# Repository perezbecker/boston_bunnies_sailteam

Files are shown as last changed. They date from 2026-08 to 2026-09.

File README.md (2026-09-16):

# Boston Bunnies Sail Team

Boat designs of the Boston Bunnies Sail Team — small, printable, self-steering sailing
models. Each boat is a parametric FreeCAD macro plus the spec and renders that go with
it.

## Fleet

| Boat | Current | What it is |
|---|---|---|
| [**Lahar**](boats/lahar/) | v2 one-piece prototype | Rounded deck-down body with attached amas, beams and skeg. 220 mm, approximately 318 g all-up, solid vane, four-bolt yard clamps, keyed steering mounts and MK4S files. |

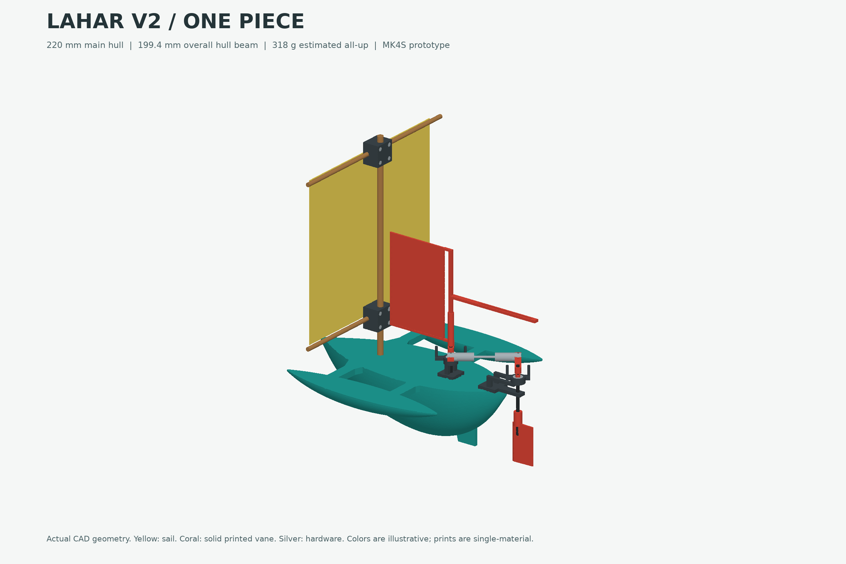
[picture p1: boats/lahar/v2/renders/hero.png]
Lahar v2


## Repository layout

```
boats/<name>/
  README.md          current-version entry point and version history
  v2/                all assets for the current prototype
    cad/             parametric macro, FreeCAD/STEP files and generation scripts
    docs/            design and assembly guide
    print/           STLs, self-contained 3MFs and printer-specific G-code
    renders/         CAD-derived reference views
    reports/         software checks and engineering estimates
  versions/v1/       frozen previous assets, including their original print jobs
```

The boat README points to the current version. Starting with Lahar v2, current
assets live in an explicit version directory, as requested for this prototype.
The source is [boats/lahar/v2/cad/lahar.FCMacro](boats/lahar/v2/cad/lahar.FCMacro).
Superseded assets remain under `versions/`; never rebuild or overwrite the archive.

## Working on a design

The macro is the single source of truth. Everything else — the dimensions in the spec,
the figures printed on the renders — is a snapshot derived from it. To change a design,
edit the parameter constants at the top of the macro and regenerate, rather than
hand-editing the derived numbers downstream. Numbers that get hand-patched in one place
and not another are how a spec and a render end up disagreeing about the same boat.

See [boats/lahar/versions/README.md](boats/lahar/versions/README.md) for preservation
rules. A valid model and completed slice do not prove watertightness or sailing
performance; each version records its outstanding physical tests.

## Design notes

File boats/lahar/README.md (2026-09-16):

# Lahar

A small mechanical self-steering downwind trimaran. No electronics.

**Current design: [v2 one-piece prototype](v2/README.md), revised 2026-09-15.**
The enclosed main hull, amas, beams and skeg print together **deck-down**, with
continuous rounded bottoms and no glued lids or ama joints. The body is 220 mm
long, 199.4 mm wide, and the boat is approximately 318 g nominal all-up. A solid
printed vane, two four-bolt yard clamps and recessed steering-mount guides are
included. All assets are together in [v2](v2/).

Lahar v2

## Build v2

- [MK4S printing instructions](v2/instructions.md)
- [Design, material reuse and assembly](v2/docs/design-spec.md)
- [Clamp and keyed-mount details](v2/renders/assembly-details.png)
- [FreeCAD assembly](v2/cad/Lahar_v2.FCStd) and [source macro](v2/cad/lahar.FCMacro)
- [USB G-code](v2/print/usb/) and [PrusaSlicer projects](v2/print/projects/)
- [Renders](v2/renders/) and [validation reports](v2/reports/)

Files are for the confirmed **MK4S, stock 0.4 mm high-flow nozzle, PLA, smooth
PEI, no MMU**. All parts fit in two jobs. Print the steering/clamps/coupon job
first, check fit, then print the body. Software checks passed; the prototype
has not been physically printed, seal-tested or sailed. The clevis's fork gap
still needs a fit check. Do not use v1's CORE One+ G-code on the MK4S.
Both yard clamps together need eight M2 x 16 socket-cap bolts and eight standard
M2 hex nuts. The steering stands locate in their recessed keys and are glued
to the deck; there are no screw holes into the hull.

## Version history

| Version | Status | Record |
| --- | --- | --- |
| [v2](v2/README.md) | Current one-piece prototype; software checked | Integrated rounded body, solid vane, two four-bolt clamps, recessed steering guides and two MK4S jobs |
| [v1](versions/v1/) | Archived; physically printed by the owner | Original assets preserved unchanged; [field observations](versions/v1/FIELD-NOTES.md) record leakage and fit problems |

The older pre-audit draft remains in git history at `4af5a90`; it was never a
separate printed version. See the [versioning rules](versions/README.md).

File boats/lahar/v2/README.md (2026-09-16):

# Lahar v2

Downwind trimaran prototype for the **Prusa MK4S, stock 0.4 mm high-flow nozzle,
ordinary PLA, smooth PEI, no MMU**. Prepared 2026-09-15.

**One-piece revision:** the enclosed main hull, both amas, beams and skeg print
together, upside down, with a continuous rounded exterior. There are no separate
lids or ama joints. This replaces the earlier modular v2 draft.

**Rigging update:** the wind vane is now solid printed plastic, both yards have
four-bolt clamp sets, and both steering stands have matching recessed deck keys.
Use the updated body and steering jobs together. The clamps need **eight M2 x 16
socket-cap bolts and eight standard M2 hex nuts** in total, supplied separately.

**Software-validated, not physically printed or sailed.** Watertightness and
steering authority are acceptance tests, not promises from a CAD model.
Print the combined small-parts job first and use its coupon to check fit before
printing the body. The clevis's internal fork gap is still unknown.

Lahar v2 assembly

## Start here

- [Printing instructions](instructions.md): two USB jobs, fit checks, and MK4S setup.
- [Design and assembly guide](docs/design-spec.md): sealing, linkage, weight budget, and test procedure.
- [Clamp and steering-mount details](renders/assembly-details.png): exploded assembly views.
- [Native FreeCAD assembly](cad/Lahar_v2.FCStd) and [STEP assembly](cad/Lahar_v2.step).
- [Parametric source macro](cad/lahar.FCMacro): edit parameters here to regenerate.
- [G-code](print/usb/), [self-contained 3MF projects](print/projects/), and [16 print-oriented STLs](print/stl/).

## What changed

The body restores v1's integrated, deck-down construction. Smooth half-ellipse
lofts form all three rounded hulls. The CAD has a measured **1.8 mm minimum
skin**, 0.9 mm ribs and 46 enclosed flotation cells. Hidden 45-degree roofs
close to a 0.6 mm gap, avoiding broad unsupported closures. Four perimeters
replace v1's two. The final body slice has no warnings or removable supports.
The rudder shaft stays outside the hull, eliminating that wet penetration.
Leak-testing is mandatory; a thin external seal coat may still be needed.

The quarter-chord rudder has **10.7 mm minimum clearance over its complete swept
envelope**. Both stocks use the existing 623ZZ bearings with short, loose lower
guides and inner-race spacers. The clevis tabs are **1.8 mm thick with 2.3 mm
holes**. A **64 x 96 mm solid vane with a 1.0 mm web** restores the printed blade,
with about 4.5 times v1's aerodynamic area-times-lever. Its extended counterweight
slot accommodates the extra weight. The existing 45 mm rod and clevises
form a nominal 64 mm pin-to-pin linkage; actual insertion depth needs checking.

Each yard has three printed clamp pieces and four bolts/nuts, holding the existing
6 mm mast and 4 mm yard without intersecting the rods. The steering stands fit
distinct asymmetric recesses with 1.8 mm of intact hull backing. Dry-fit them in
their keys, then bond the bases; the recesses are not snap fasteners or screw holes.

This is a conservative, heavier prototype: **220 x 199.4 x 65.2 mm body print,
about 318 g nominal all-up**, rather than v1's approximately 106 g target.
The forward hull sections have been filled out to carry the clamps and solid
vane. Minimum deck freeboard is calculated at 13.9 mm nominally and 12.4 mm at
a 350 g loading check. These are static estimates, not a certified payload or
wind rating. At 10 degrees of heel in the conservative-weight case, the low-side
deck is almost awash. Use sheltered water and verify the physical boat before sailing.

## Printer files

| Job | Time estimate | PLA including waste |
| --- | --- | --- |
| Steering, both clamp sets and fit coupon, 15 parts | 6 h 5 min | 58.03 g |
| One-piece body with locating recesses | 26 h 3 min | 238.82 g |

Total: **32 h 8 min and 296.85 g**, including the coupon and removable waste.
All 16 parts are included exactly once; only their placement and job grouping
changed. The body stays on its own bed. Have 350 g of PLA available.
Colors in the renders distinguish materials; all G-code jobs are single-material.

**The slicing is not identical to v1.** Deck-down printing and 0.15 mm layers are retained,
but the MK4S-specific printer preset, shell construction, perimeter count, solid
layers, and support layout are different. Never run the archived CORE One+ G-code
on the MK4S. The MK4S print volume is **250 x 210 x 220 mm**.

## More views and evidence

[One-piece body and print orientation](renders/one-piece-body.png) | [Hull section](renders/hull-section.png) |
[Steering](renders/steering-gear.png) | [Clamps and mount guides](renders/assembly-details.png) |
[Print layouts](renders/print-layouts.png)

The [CAD checks](reports/cad-validation.json), [slicing checks](reports/print-validation.json),
[engineering estimates](reports/engineering.json), and [render checks](reports/render-validation.json)
record what was verified. No physical hardware fit, seal, bearing friction, or
on-water steering test has been performed.

The untouched predecessor is in [versions/v1](../versions/v1/).

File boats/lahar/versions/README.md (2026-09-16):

# Archived Lahar versions

## v1

[v1](v1/) preserves the complete previous design: its original README, printing
instructions, macro, export and slicing scripts, design specification, renders,
STLs, two 3MF projects and two CORE One+ G-code files. All original files were
compared byte-for-byte before the root-level duplicates were removed.

[FIELD-NOTES.md](v1/FIELD-NOTES.md) records the owner's 2026-09-15 observations
and why v2 replaces it. The archived original README and instructions are
historical snapshots; their older "not yet printed" wording and root-relative
rebuild examples have deliberately not been rewritten.

**Do not rebuild inside this archive.** Its scripts overwrite generated files
beside themselves. Copy a version to a separate work area before investigating
or rebuilding it. Never run these CORE One+ jobs on the MK4S.

## Current-version layout

The current design is [../v2](../v2/). Starting with v2, each active iteration
has its own explicit directory containing all its assets, and the boat README
points to it. This replaces v1's convention of putting active CAD and print
folders directly at the boat root.

## Preserve a future version

1. Record the physical observations, measured mass, water uptake, hardware
   dimensions and steering tests before changing anything.
2. Preserve the complete previous directory, including instructions, reports
   and printer files, under `versions/vN`. Do not copy only CAD and renders.
3. Verify every original file against the archive before removing a duplicate.
4. Create the next active directory, update the macro/document version, and
   regenerate its CAD, meshes, projects, G-code, reports and renders together.
5. Update the boat README and fleet entry. Clearly distinguish software checks
   from physical validation, and identify the exact printer/nozzle/material.

An archive's original assets are immutable. Add a separate field-notes file for
later observations instead of rewriting old evidence or hand-patching old G-code.

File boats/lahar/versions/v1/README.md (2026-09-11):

# Lahar

A **self-steering downwind trimaran** — a 200 mm, ~106 g model yacht that prints as one
piece, carries a square sail on a dowel mast, and holds its course with a mechanical
wind vane driving the rudder. No electronics.

**Current version: v1** (designed, not yet printed).

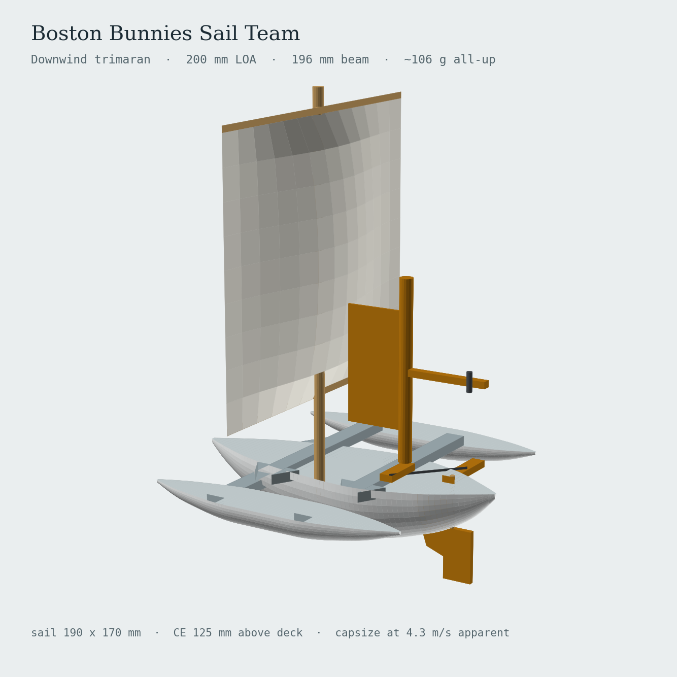
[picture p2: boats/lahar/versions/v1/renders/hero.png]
Hero render


## Files

| Path | What it is |
|---|---|
| [`cad/lahar.FCMacro`](cad/lahar.FCMacro) | Parametric FreeCAD macro — generates every printed part |
| [`instructions.md`](instructions.md) | CORE One+ USB printing instructions, settings, and first-print caveats |
| [`print/usb/`](print/usb/) | Two ready-sliced G-code jobs for a CORE One+, stock 0.4 mm high-flow nozzle, PLA, smooth PEI |
| [`print/projects/`](print/projects/) | Editable PrusaSlicer projects with settings and side-float infill modifiers |
| [`print/stl/`](print/stl/) | Five checked, print-oriented meshes in millimetres |
| [`cad/export_print.py`](cad/export_print.py), [`cad/slice_print.py`](cad/slice_print.py) | Rebuild the meshes, projects, and printer files |
| [`docs/design-spec.md`](docs/design-spec.md) | Design spec and build guide: dimensions, weight budget, rigging, tuning, BOM |
| [`renders/`](renders/) | Reference renders |
| [`versions/`](versions/) | Superseded iterations (empty — v1 is the first) |

## Print from a USB drive

For the confirmed **Prusa CORE One+, stock 0.4 mm high-flow nozzle, PLA, and smooth
PEI sheet**, use the two files in [print/usb](print/usb/) and follow
[instructions.md](instructions.md). No further slicing is needed for that setup.
The body takes about 4 h 27 min and steering about 1 h 20 min.

These are **first-test files, not physically validated prints**. The hollow body
still produces a PrusaSlicer "Floating bridge anchors" warning; read the guide's
caveat and inspect its Preview before printing. The steering parts include
removable supports. Assembly still needs the hardware and rig in the design spec.

## Generate from CAD

1. Open FreeCAD (the current export was checked with 1.1.3) and go to **Macro → Macros… → Execute**,
   pointing at `cad/lahar.FCMacro`.
2. The macro builds five parts in a document named `Lahar_v1`:
   `Trimaran_Body`, `Rudder_Blade`, `Rudder_Tiller`, `Vane_Paddle`, `Vane_Arm`.
3. Export them as STL. The macro has a commented-out export block at the bottom if
   you'd rather batch it.
4. Slice the body **deck-down** — flip 180° about X. Everything on deck is a recess,
  so the intended orientation needs no external supports; internal bridging still
  needs a test print. Main hull at 4 % infill, amas at 0 % — they are floats, and
  the weight budget assumes it. The ready-made STLs are already flipped.
5. Build the sail and rig from the [spec sheet](docs/design-spec.md); mast, yards,
   bearings and pushrod are off-the-shelf parts.

To change the design, edit the `PARAMETERS` block at the top of the macro and re-run.
Hull stations, ama placement, mast position, skeg size and arm hole spacing are all
driven from there.

## Principal dimensions

| Item | Value |
|---|---|
| Length overall | 200 mm |
| Beam overall | 196 mm |
| All-up weight | ~106 g |
| Design waterline | ~16 mm below deck, amas clearing by 1.4 mm |
| Sail | 190 × 170 mm square, on mast + two yards |
| Print footprint | 200 × 196 × 46 mm — fits a 220 × 220 bed |

Full numbers, weight budget and bill of materials live in [`docs/design-spec.md`](docs/design-spec.md).

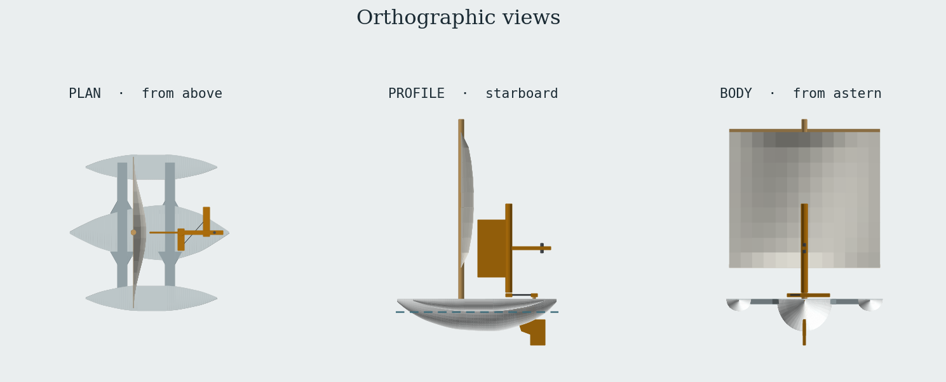
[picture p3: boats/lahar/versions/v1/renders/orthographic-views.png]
Orthographic views


## How the steering works

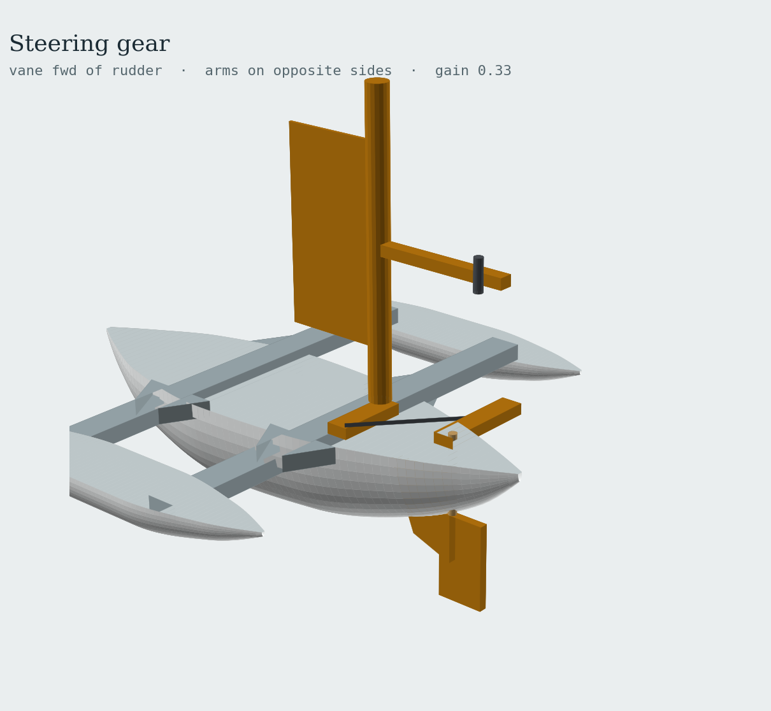
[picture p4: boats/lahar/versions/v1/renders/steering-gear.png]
Steering gear


*(Linkage geometry is current; the hull in this view predates the hull refinement.)*

A wind vane forward of the rudder is linked to the tiller by an adjustable pushrod.
Three details make or break it, and all three are easy to get wrong:

* **Arms on opposite sides.** Vane arm to port, tiller arm to starboard. The reversal
  is what makes a course error push the bow *back*. Same side and the boat spirals.
* **Balance the vane.** Slide the M3 screw along the counterweight slot until the
  paddle sits indifferent at any angle with the boat heeled 10–15°. An unbalanced
  vane steers to the low side, not to the wind.
* **Gain = vane hole radius ÷ tiller hole radius.** Start at 6/18 ≈ 0.33. Fishtailing
  means go smaller; lazy wandering means go larger.

The single centerline skeg supplies the damping — there are no fins on the amas.
Sail effort sits forward at 40 % LOA and lateral resistance sits aft, a 21 % LOA
separation, which is what keeps the boat tracking downwind instead of sliding sideways.

Below about 0.7 m/s of apparent wind the vane has too little torque to hold a course
and will wander. That is inherent to a vane this size, not a build fault.

## Stability, and why the rig is short and wide

The amas *are* the stability — the main hull alone has negative GM and will loll a
degree or two until one ama takes up. Normal trimaran behaviour.

Sail centre of effort sits 125 mm above deck. One fully buried ama gives 30 mN·m of
righting moment, which sets the capsize threshold at roughly 4.3 m/s apparent wind in
a 30° gust; comfortable sailing is up to ~3.3 m/s. Because apparent wind downwind is
true wind *minus* boat speed, the boat is most vulnerable at the moment you release
it, before it accelerates.

Two findings drove the current proportions:

* **Trading sail height for width is free stability.** An earlier 160 × 200 sail on
  a 330 mm mast put the CE at 190 mm and capsized at ~3.5 m/s. Same area at 190 × 170
  on a 250 mm mast raised the threshold to 4.3 m/s — 21 % more wind for free.
* **Lengthening the main hull does nothing for heel resistance.** BM_T = I_T/V and
  both scale with length, so stretching 200 → 280 mm leaves BM_T unchanged while
  adding 40 % wetted area. Heel resistance is a beam property. The amas were
  lengthened to 165 mm and their sections grown instead — +58 % righting moment
  inside the same footprint.

## Design notes

The trimaran was chosen over a monohull, catamaran or proa because the amas carry no
load, so they need no precision to work. The amas are double-ended (transoms only pay
off above Froude ≈ 0.5, far beyond this scale) and finless. A cross-sail was rejected
for destabilizing the vane, and a keel for adding harmful lateral area downwind.
Upwind capability is deferred — it would need a cambered sail, a daggerboard forward,
and the CE/CLR order reversed.

The design was settled by a full end-to-end audit — mass build-up, equilibrium
waterline, trim, stability, balance — which raised the weight budget from an optimistic
95 g to 106 g, widened the main hull and shifted its volume aft to cure a 5.7° stern
squat, re-proportioned the amas, and deepened the skeg and rudder to keep grip under
the deeper hull. The boat floats with a deliberate +2.3° stern-down trim, which
lightens the bow and helps it track.

Background and the reasoning behind these choices:
[design conversation](https://claude.ai/share/8d004267-fff6-457e-bb1f-0c273a21cccd)
(25 Aug 2026).

## Version history

| Version | Status | Notes |
|---|---|---|
| **v1** | current | Audited design: 196 mm beam, ~106 g, 190 × 170 sail, 165 mm amas. Not yet printed. |

An earlier pre-audit draft (191 mm beam, ~95 g, 160 × 200 sail on a 330 mm mast) was
superseded before anything was printed and is not carried as a version. It remains in
git history at commit `4af5a90` if you ever want to look at it; the stability section
above explains why its rig was cut down.

See [`versions/README.md`](versions/README.md) for how the next iteration gets cut.

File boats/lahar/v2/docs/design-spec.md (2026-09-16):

# Lahar v2: design and assembly

Boston Bunnies Sail Team, 2026-09-15. Source of truth:
[lahar.FCMacro](../cad/lahar.FCMacro). Generated estimates are in
[engineering.json](../reports/engineering.json).

**This is an untested physical prototype.** The design addresses v1's reported
leaks, rudder interference, clevis mismatch and steering-friction concerns.
No software check can certify an FDM hull as watertight or establish the friction
of the user's bearings. Complete the acceptance tests before open-water use.

## Design decisions

1. **Restore v1's one-piece, upside-down construction.** The main hull, both
   amas, two crossbeams, gussets and skeg form one enclosed solid. The continuous
   deck sits on the print bed; all three rounded bottoms grow upward. There are
   no separately printed lids, bonded ama joints or skeg attachment pad. This
   revision replaces the earlier modular v2 draft at the owner's request.
2. **Thicker skins and printable hidden closures.** Smooth half-ellipse lofts
   preserve the rounded exterior. Scaled internal cavities leave a CAD-measured
   minimum 1.8 mm skin, including the deck. Four perimeters replace v1's two.
   Internal 0.9 mm ribs at 12 mm spacing divide the hulls into 46 closed cells:
   18 in the main hull and 14 in each ama. Each cell has a 45-degree internal
   roof closing to a 0.6 mm gap. Only these hidden roofs are angled; the outside
   remains rounded. This avoids the floating bridge anchors encountered with
   simply hollowing the rounded body. Final slicing reports no warnings.
3. **No wet rudder penetration.** The rudder stock and its lower guide are on
   an external stern bracket. The mast well has a closed floor. Only the small
   steering stands bond onto the already closed deck. Distinct recessed keys
   locate them without screws into buoyancy chambers; those joints are not hull seals.
4. **Lower-load steering with the existing hardware.** Keep the two 623ZZ
   bearings and carbon stocks. Use short clearance guides, inner-race spacers,
   a quarter-chord rudder, thin clevis tabs and indexed cranks. The vane is now
   solid printed plastic again, with a 1 mm web and an extended counterweight slot.
   There is still plain-guide and clevis friction; the system is not frictionless.
5. **Four-bolt yard clamps.** Two three-piece clamp sets attach the existing
   6 mm mast to the two 4 mm yards. Each uses four M2 x 16 socket-cap bolts and
   four captive M2 nuts. The yards sit just forward of the mast so the rods
   do not intersect. Added plastic, hardware and counterweights are included
   in the revised mass calculation; the hull's forward sections are slightly fuller.

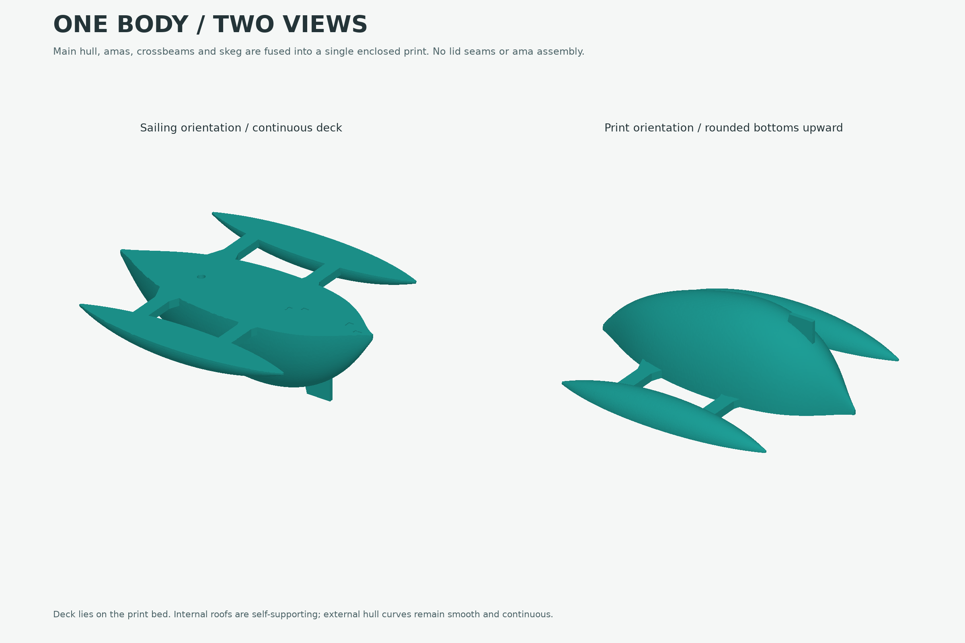
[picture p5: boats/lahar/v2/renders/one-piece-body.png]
One-piece body in sailing and print orientation


## Dimensions

Coordinates are millimetres: X runs bow to stern, Y is positive to starboard,
Z is upward. The continuous deck is Z=1.2, retained from the steering layout.

| Item | v2 |
| --- | --- |
| Main hull, measured mesh | 220 long x 79.46 maximum beam x 64.21 deep |
| One-piece body print bounds | 220 x 199.41 x 65.20 |
| Amas, measured mesh | 178 x 33.41 x 16.72; bows at X=22; centerlines Y=+/-83 |
| Main hull bottom | Continuously rounded; lowest mesh point Z=-63.01 |
| Minimum outer skin / continuous deck | At least 1.8 / 1.8 |
| Integral crossbeams | 12 x 180 x 6; leading edges X=60 and 132, flush with deck |
| Internal ribs / roofs | 0.9 thick, 12 pitch; 45-degree slopes, 0.6 final gap |
| Mast well | X=70; bore 6.4; insertion 24; closed floor 1.8 |
| Vane / rudder axes | X=154 / 234; Y=0 |
| Steering mount keys | Four blind recesses, 0.8 deep; matching feet 0.6 high; 1.8 minimum backing |
| Bearings | 623ZZ, 3 x 10 x 4; pockets 10.2 x 4.2 |
| Bearing top / linkage tab bottom | Z=19.8 / 24.2 |
| Lower guide bore | 3.8, short and accessible |
| Printed stock sockets | 3.2 |
| Rudder | 24 chord x 40 span; Z=-28 to -68; 25% chord pivot |
| Rudder cylindrical boss | 8 diameter, 14 high; Z=-30 to -16 |
| Full rudder sweep clearance | 10.71 minimum to the complete body and integral skeg |
| Integral skeg | X=150 to 184, 3 thick; tip Z=-64 |
| Solid printed vane | 64 x 96 area, 1.0 web, 1.2 rim; no film |
| Vane aerodynamic center lever | 40 from axis |
| Vane counterweight slot | 35 to 95 from axis |
| Vane / tiller gain holes | 12, 15, 18 / 30, 36, 42 |
| Clevis tabs / pivot holes | 1.8 thick / 2.3 diameter |
| Neutral pin-to-pin length | 64 with the 12/36 hole pair |
| Assembled length including centered rudder | 252 |
| Neutral length including longer counterweight arm | 256 |
| Yard centers | X=62.6; Z=40 and 210; 7.4 forward of mast |
| Yard clamps | Two sets of three 22 x 22 pieces; four M2 bolts/nuts per set |
| Clamp groove diameters / split gaps | 6.2 mast, 4.2 yard / 0.4 on each side of middle saddle |

The whole 220 x 199.41 mm body fits the **250 x 210 mm MK4S bed** with its brim.
Only the steering parts, clamp pieces and fit coupon print separately. The
rudder and longer counterweight arm extend beyond the printed body.
Loft interpolation makes measured dimensions differ slightly from station values.

## Weight and flotation

| Component group | Nominal mass |
| --- | --- |
| One body, eight steering parts and six clamp pieces, at PLA density 1.24 g/cm3 | 277.61 g |
| Mast, two yards, sail and rigging | 9.69 g |
| Carbon stocks | 1.52 g |
| Two 623ZZ bearings | 3.40 g |
| Metal clevises, screws and 45 mm rod | 6.00 g |
| Eight M2 x 16 clamp bolts and eight M2 nuts | 5.60 g |
| Fore-aft counterweight and lateral balance nuts allowance | 4.50 g |
| Adhesive and seal coat allowance | 10.00 g |
| **Nominal all-up** | **318.32 g** |

Hardware masses, wood density, cloth weight and seal-coat mass are assumptions,
not measurements. Cloth is budgeted at 30 g/m2. Weigh the actual parts.
The body alone is 239.77 g by CAD volume; both clamp sets together are 16.49 g.
The complete solid vane including its spine and counterweight arm is 10.33 g.
The two print jobs consume 296.85 g, including the coupon, supports and brims.
The coupon now shares the steering bed, but is never part of the boat's displacement.
Subtracting its 8.57 g CAD material estimate leaves 288.28 g; counting all the
remaining waste as if it stayed on the boat gives a conservative **328.99 g** case.
Repacking does not change the nominal assembled mass or center of gravity.

| Fresh-water case | Waterline at X=110 | Trim | Minimum deck freeboard | Lowest ama bottom |
| --- | --- | --- | --- | --- |
| Nominal 318.32 g | Z=-14.81 | 1.11 deg bow-down | 13.88 mm | 0.74 mm immersed |
| Conservative 328.99 g | Z=-13.96 | 0.96 deg bow-down | 13.32 mm | 1.59 mm immersed |
| 350 g loading check | Z=-12.41 | 0.65 deg bow-down | 12.36 mm | 3.12 mm immersed |

These are static calculations on closed exterior meshes generated from the CAD
with 0.04 mm deflection. Each mesh volume is checked against its CAD envelope.
Trimesh caps the submerged surface at the waterplane and SciPy solves displacement
and fore-aft balance. Required residuals are below 0.05 g and 0.05 mm; this is
solver tolerance, not a claim of equivalent physical accuracy. CAD boolean
integration was replaced because it produced noisy, non-converging derivatives.

The deeper main hull and fuller forward sections account for the new weight
and the mast clamps' forward location. This is heavier than both v1 and the earlier v2 drafts; no
speed or minimum-wind improvement is claimed from the hull change. Calculations
use the nominal CG and omit appendage buoyancy conservatively. Different hardware,
ballast, waves, wood water uptake and leaks change the answer. Do not reuse v1's
106 g budget or its claimed wind limit.

The planning-load model has restoring moments at both signs of 5 and 10 degrees
of heel. At 10 degrees in the conservative-weight case, the low-side deck has
only about **0.4 mm freeboard**, effectively awash in small ripples. Wave and
splash tolerance need physical testing. This is not a capsize angle or wind
rating. Use **350 g as a re-evaluation threshold**, not a certified carrying
capacity. Begin in sheltered, steady conditions with a retrieval line.

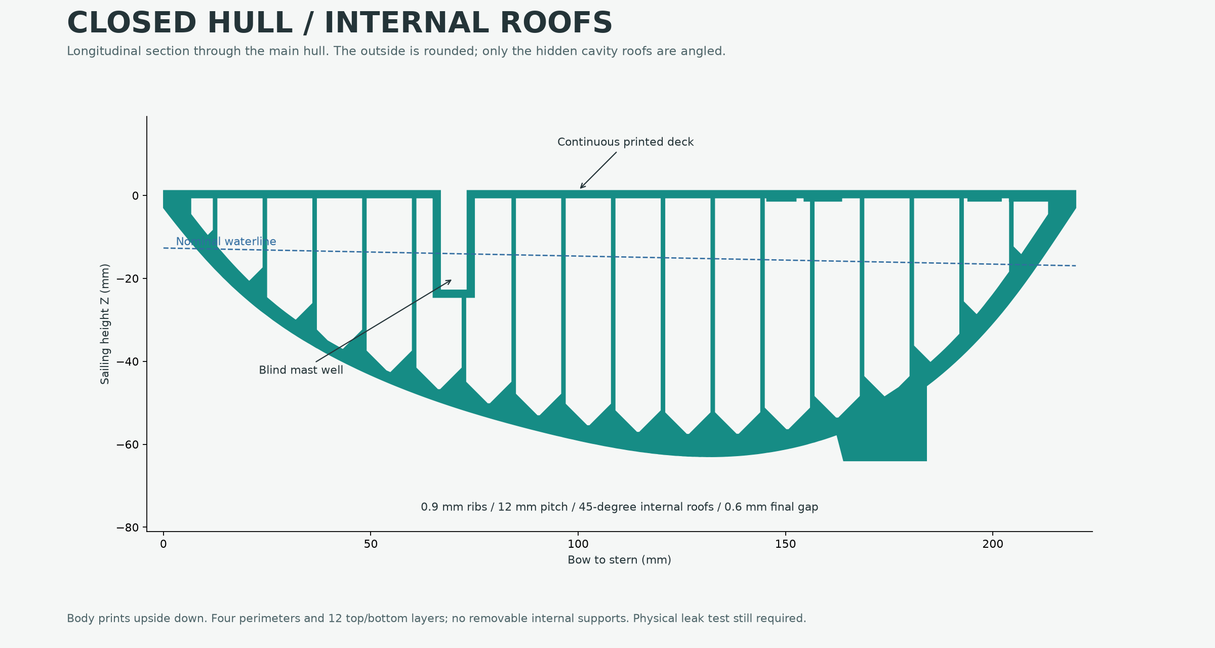
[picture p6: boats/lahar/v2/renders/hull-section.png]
Main hull section


## Clevis and pushrod

Source: the user's [MECCANIXITY listing, ASIN B0D5L9FNG2](https://www.amazon.com/dp/B0D5L9FNG2),
accessed 2026-09-15, plus the dimension image supplied in the conversation.

| Interface | Evidence | v2 response |
| --- | --- | --- |
| 25 mm overall clevis length | Listing and dimension image | Include a full-length connector envelope |
| 8 mm outside width | Listing and image | Check 8 mm barrel clearance, not just the pivot pin |
| 2 mm rod-entry bore / M2 size | Image and title | Reuse the user's M2 rod; verify actual insertion and retention |
| M2 x 8 pivot screws | Listing package description | 2.3 mm clearance holes instead of v1's 1.6 mm holes |
| M3 grub screws | Listing and image | Retain the rod with the supplied hardware as appropriate |
| Internal fork gap | **Not dimensioned** | 1.8 mm tabs, tested first on a 1.5/1.8/2.1 mm coupon |
| Pivot-to-rear distance and usable rod insertion | **Not dimensioned** | Verify the assembled 64 mm pin spacing before bonding stands |

The product's M2 label does not define its fork gap. Its 8 mm width is outside
width, not an 8 mm slot. The marketplace's generic material field also conflicts
with its metal title and photo; it is not a manufacturing drawing.

The rod length is **45 mm, as reported by the user**, not 45 mm pin-to-pin.
For example, a 22 mm rear-to-pin distance on each clevis would require
12.5 mm insertion at each end to give 64 mm pin spacing:

$$L = 45 + a_1 + a_2 - e_1 - e_2.$$

Here $a$ is rear-to-pin distance and $e$ is insertion. That example is an
illustration, not a verified internal clevis dimension. Both retaining positions
must engage the rod securely. Do not force an unthreaded shank through a tapped
portion or leave the rod barely engaged to obtain the target length.
If your assembled link cannot reach 64 mm securely, stop and revise the axis
spacing with that measurement; do not force the linkage or bond misaligned stands.

The CAD collision check uses a conservative 8 mm diameter barrel extending
8-23 mm from the pin. The rendered clevis fork is schematic; its assumed opening
is not evidence of the real gap. Check the fork cheeks, screw heads and barrels
physically through the full travel.

## Steering and light wind

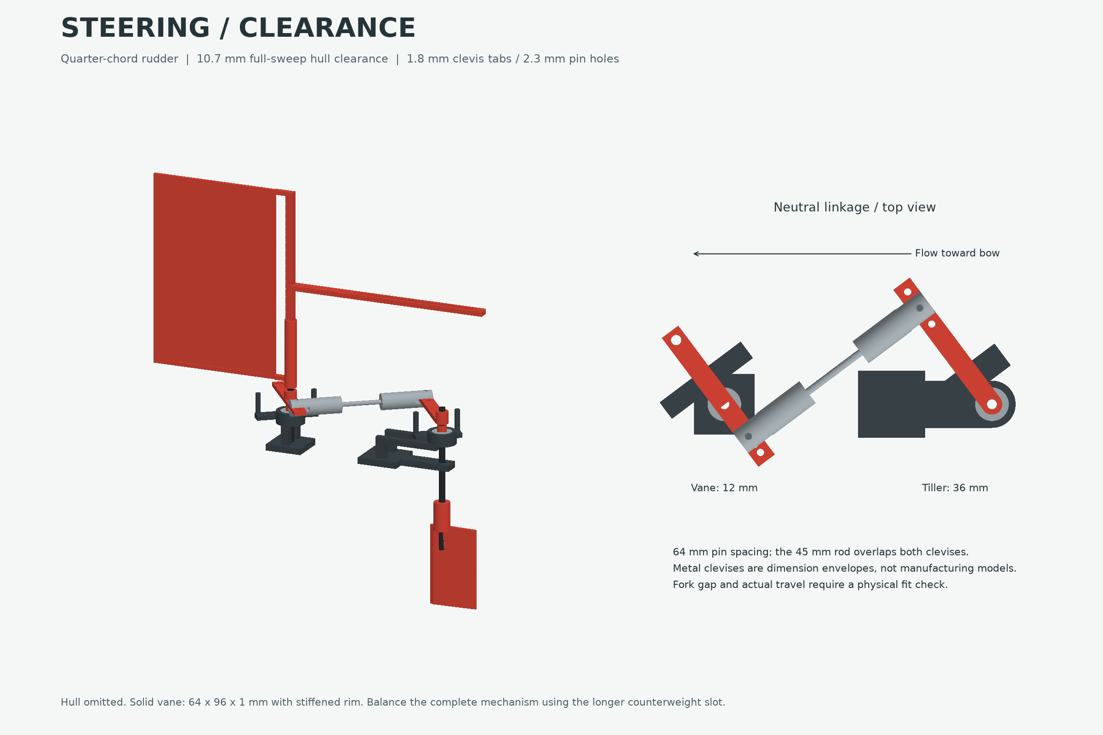
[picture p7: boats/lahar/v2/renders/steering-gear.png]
Steering geometry


The vane is **solid printed plastic again**, with a 1.0 mm web matching v1's
blade thickness and a slightly thicker rim. It retains v2's larger 64 x 96 mm
area; its area times lever is **4.51 times v1's** under the same aerodynamic
coefficient. The object retains the name `Vane_Frame`, but no film is required.
It remains upstream of the sail while running downwind.

The larger solid paddle is not as light as the film version: its complete
printed mass is about 10.33 g. The 35-95 mm counterweight slot provides enough
reach for approximately 3 g of balancing hardware near 91 mm for the paddle
alone. This is a starting estimate, not a balance prescription for the complete
linkage. Rebalance with the stock, arm and metal clevis connected, including
the lateral imbalance. The mass budget allows another 1.5 g of lateral nuts.
More inertia and bearing load mean that increased area does not guarantee
good response in very light wind.

At neutral, the vane arm points **port and aft**; the tiller points **starboard
and forward**. Both are indexed 36.87 degrees from the transverse direction.
Do not straighten them to lie exactly across the boat. With the 12/36 mm holes,
their pin positions are (161.2, -9.6) and (212.4, 28.8), respectively. The rod
is perpendicular to the crank radii at neutral, maximizing mechanical leverage
and avoiding v1's short, oblique arrangement.

The exact four-bar calculation gives a neutral rudder/vane ratio of **-1/3**.
Vane travel from -40 to +40 degrees produces approximately +12.54 to -12.21
degrees of rudder rotation. The vane stops limit working travel; the rudder's
separate +/-25 degree stops are a backup when disconnected. Clearance was
checked every 2 degrees and against the rudder's entire cylindrical swept bound.
Only the default 12/36 configuration has this validation; changing holes needs
a new clearance check and calibration.

Your concern about downwind authority is justified. On a dead run,
$V_{app} \approx V_{true} - U_{boat}$, and vane torque falls with $V_{app}^2$.
The water-loaded rudder does not become load-free just because apparent wind
is small. Balancing and reducing friction help, but cannot remove that limit.

Illustrative estimates at a 10 degree vane error:

| Apparent wind | Vane torque |
| --- | --- |
| 0.5 m/s | 0.013 N mm |
| 0.75 m/s | 0.029 N mm |
| 1.0 m/s | 0.052 N mm |
| 1.5 m/s | 0.118 N mm |

These use air density 1.225 kg/m3 and an assumed normal-force coefficient
$C_N = 2\sin(\alpha)$. A 0.6 m/s boat-speed example, water lift slope 2.5/radian,
and 1-6 mm residual rudder hinge-moment arm reflect roughly 0.008-0.050 N mm
back to the vane. Add a **target, not a measured fact**, of 0.010 N mm total
breakaway friction. The resulting illustrative break-even apparent wind is
0.59-1.07 m/s. Low-Reynolds-number coefficients, bearing drag and clevis friction
are uncertain; this is not a guaranteed operating range.

The quarter-chord pivot reduces expected water load, but does not guarantee
perfect hydrodynamic balance. Start tests in steady conditions with margin,
not at the calculated break-even point. The 0.6 m/s example is a load case,
not a prediction that this heavier boat will achieve that speed.

This is the preferred **simple iteration using the existing hardware**, not a
claim that direct vane steering is best in every condition. A water-powered servo
tab or servo-pendulum could amplify a weak vane signal, but would add another
precision hinge, linkages, drag and a separate hydrodynamic tuning problem. It
was not implemented as an unverified extra mechanism here. If the loaded test
still fails, do not just increase the vane/rudder gain: that also increases the
rudder torque reflected to the vane.

## Materials to reuse

| Quantity | Material |
| --- | --- |
| 2 | Existing 623ZZ bearings, 3 x 10 x 4 mm |
| 1 | Existing 6 mm hardwood mast, about 250 mm long |
| 2 | Existing 4 mm dowel yards, about 210 mm long |
| 2 stocks | Existing 3 mm carbon rod; nominal 62 mm vane and 72 mm rudder |
| 1 + 2 | Existing MECCANIXITY M2 45 mm rod and metal clevises with their screws |
| 1 set | Existing M3 x 16 counterweight screw and spare nuts |
| 8 + 8 | M2 x 16 socket-cap bolts and standard M2 hex nuts for the yard clamps, four of each per set |
| As needed | Existing light sail material, thread and CA for tack assembly |
| Thin application | PLA-compatible waterproof adhesive/seal coat, e.g. suitable two-part epoxy |

**Already-cut v1 stocks of 60 and 70 mm can be reused:** they retain approximately
30 mm engagement in the vane frame and 22 mm in the rudder socket, respectively.
The CAD references show the slightly longer nominal lengths. Do not buy larger
bearings, different dowels or a replacement linkage just for this iteration.

The vane now prints complete: do not attach film. Weigh your existing balance
screw and nuts, and position them in the longer slot. Lash spare nuts to the
lateral balance ear using rigging thread if needed. The clamp hardware is the
only newly specified set of metal fasteners; it is not part of the printed jobs.

An external sealer is optional if the soak test shows porosity; there are no
lid seams to glue. Use appropriate adhesive for the steering stands and stock
sockets. Follow the adhesive's PLA-compatibility, curing and ventilation instructions;
use appropriate gloves and eye protection, and keep adhesive out of bearings.

## Yard clamps

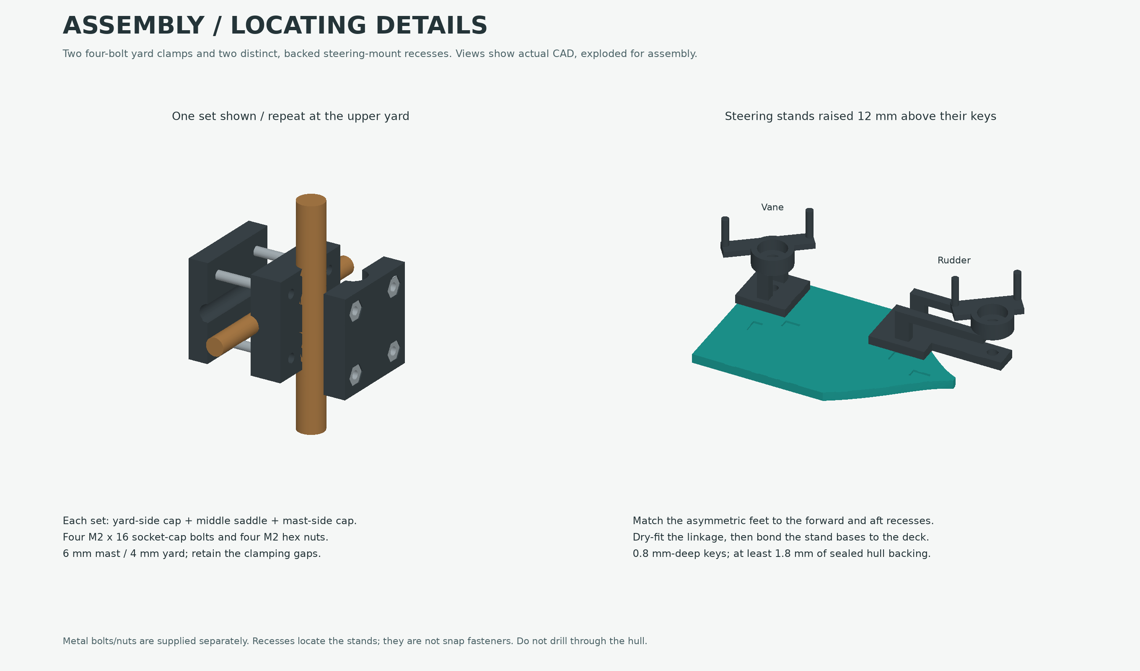
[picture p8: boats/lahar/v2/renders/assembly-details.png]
Exploded yard clamp and steering-mount guides


There are **two complete sets**, one at each yard. Each set contains a yard-side
cap, a middle saddle and a mast-side cap, plus **four M2 x 16 socket-cap bolts
and four M2 hex nuts**. The steering job already prints both sets; do not print
it twice. Lower and upper sets have the same geometry and are interchangeable.
Their CAD names start with `Lower_Yard_` and `Upper_Yard_`.

Nominal hardware: standard M2 socket-cap head about 3.8 mm diameter and 2 mm high;
plain M2 nut about 4 mm across flats and 1.6 mm thick. The prints provide 4.2 mm
head recesses, 4.2 mm-across-flats nut traps and 2.3 mm through holes. Nyloc,
flanged or unusually thick nuts are not the modeled hardware. Bolt length is
measured under the head. CAD gives 0.5 mm of bolt beyond the complete nut before
tightening. Dry-fit your actual screws and nuts before loading the dowels.

1. Remove support and burrs from the grooves, head seats and nut pockets. The
   mast-side cap has four hexagonal recesses; seat the nuts in those outer faces.
2. Put the middle saddle between the vertical 6 mm mast and the horizontal 4 mm
   yard. Its larger groove faces aft toward the mast; its smaller groove faces
   forward toward the yard. The yard center is 7.4 mm forward of the mast, so
   the dowels remain separate rather than crossing through each other.
3. Put the yard-side cap over the yard, with its round bolt-head recesses facing
   the bow. Put the mast-side cap over the mast, nuts facing aft.
4. Pass the four bolts from the yard-side cap, through the middle saddle and
   into the four captive nuts. Start every bolt before tightening any one.
5. Set the lower yard center about **38.8 mm above the deck** and the upper
   yard center **208.8 mm above the deck** (CAD Z=40 and 210). Center each yard
   across the mast and check both yards are parallel.
6. Tighten gradually in a diagonal pattern, just until the rods are held. The
   6.2 and 4.2 mm grooves and two 0.4 mm split gaps allow slight clamping motion.
   Do not force the gaps shut, crush the dowels or bow/crack the PLA caps.
7. Lash the square sail to the yards on their forward side, keeping cloth clear
   of bolt ends and the wind vane. The rigid sheet in the render is a placement
   reference; the actual sail is flexible. Recheck clamp grip after the first soak.

## Steering mount guides

Use the matching current body and stands. Both stands now have **two asymmetric
feet** that fit the shallow recesses printed into the deck. The forward pair
locates the vane stand at X=154; the aft pair locates the long rudder stand's
base at X=194-214, with its bearing cantilevered out to X=234. The guide patterns
reject a swapped or 180-degree-reversed stand in the nominal CAD assembly.

| Recess | Center X, Y | Pocket size X x Y |
| --- | --- | --- |
| Vane, forward key | 149, -3 | 3.5 x 5.5 mm |
| Vane, aft key | 159, +3 | 5.5 x 3.5 mm |
| Rudder, forward key | 198, +3 | 4.5 x 5.5 mm |
| Rudder, aft key | 209, -3 | 6.5 x 3.5 mm |

All pockets are **0.8 mm deep**. Feet are 0.6 mm high, with 0.25 mm side
clearance and 0.2 mm clearance beneath them. Local backing leaves **at least
1.8 mm of solid hull between every recess and the nearest flotation cell**.
Bearing heights, stock heights and the 64 mm neutral linkage remain unchanged.

1. Remove support remnants from the stand feet and dry-fit each into its matching
   pair. The flat underside of the base should rest on the deck; feet must not
   bottom out and leave the stand rocking. If necessary, deburr the feet lightly.
   Do not deepen the pockets or drill through their floors.
2. With both stands sitting in their keys, fit the bearings, stocks, arms and
   the actual clevis rod. Verify secure 64 mm pin-to-pin adjustment, a centered
   rudder and free travel before applying adhesive. If the linkage cannot fit,
   stop and revise the keyed axis spacing; do not glue a stand off its guides.
3. Remove the moving parts and bearings from the gluing area. Use a thin film
   of suitable PLA adhesive under each base, place it in its keys and hold it
   square until fully cured. Keep adhesive out of the stock guides and bearings.
4. Reassemble and test motion again. The recesses locate the stands; they do
   **not** snap or bolt them down. This implements the requested recessed-guide
   option, not hull screw holes. Bonding the stands remains necessary.

## Assembly

1. Print the combined steering, clamps and coupon job, remove the brim and
   supports, and pass the [hardware fit checks](../instructions.md#fit-check-before-the-body).
   Then clear the bed and print the body. There are only two supplied print jobs.
2. Inspect the continuous deck, rounded hulls and beam transitions for gaps or
   loose extrusion. Do not cut open the hulls, remove the internal ribs, or drill
   drain holes. Amas and skeg are already attached and aligned by the print.
3. Weigh and soak-test the bare body. If it leaks, dry it thoroughly, repair
   local pores or apply a thin compatible external seal coat, and repeat the
   test. Keep the mast well and bearing bonding surfaces clean. Include any
   coating in the finished mass; do not fill the empty cells with resin.
4. Dry-fit the bearing stands in the [recessed mount guides](#steering-mount-guides).
   Assemble the rod and clevises and verify secure 64 mm pin spacing before
   bonding the stand bases. Do not screw through the buoyancy chambers.
5. Install each bearing by loading its outer race only. Align the loose lower
   guide with a straight stock. A tight pocket must be relieved or reprinted,
   not forced. Do not remove bearing shields or pack them with heavy grease.
6. Fit each 4.4 mm outer-diameter spacer on the stock above the bearing. It
   contacts the inner race only, leaving the arm and clevis clear of the housing.
   Bond the printed stock sockets to the carbon only after setting height and
   angle. Do not glue a stock to a guide, outer race or bearing shield.
7. Set the vane stock's lower end about Z=2, above the continuous deck. The nominal
    rudder stock runs Z=-40 to 32; a 70 mm stock can start at Z=-38 instead.
    Leave perceptible axial freedom, about 0.2-0.4 mm, rather than preloading
    the bearing between bonded parts. Keep glue from wicking into the bearing.
8. Attach the 12 mm vane hole and 36 mm tiller hole with the clevis screws.
    Retain the screws securely without squeezing the tabs. A loose, unsecured
    screw is not a solution to binding. Use a suitable thread-retention method
    only on its threads if needed, away from the pivot surfaces.
9. Turn the vane through its entire travel. The joints must remain free,
    barrels clear, and the rudder must reverse direction. Keep the metal
    linkage in one horizontal plane. Check the actual fork cheeks and screw
    heads, which the product drawing does not fully dimension.
10. Fit the complete solid vane and balance the **whole moving system with the
   linkage connected**. Slide the existing M3 screw/nuts along the longer fore-aft slot, and
    use spare nuts on the opposite lateral balance ear to offset the metal
    clevis. Tilt the boat 10-15 degrees about both axes: the vane must not
    consistently fall to one side. Counterweights are adjustable, not shown
    as a fixed prescription in the renders.
11. Install both [four-bolt yard clamps](#yard-clamps), reusing the 190 x 170 mm
   sail, 250 mm mast and 210 mm yards. The mast sits 24 mm into its well at
   X=70; yard centers are X=62.6, Z=40 and 210. Seal exposed wood ends. Do not
   drill through the mast well floor.
12. Weigh the finished boat, verify its waterline and balance, then perform the
    following tests. Do not add ballast automatically to match the nominal mass.

## Acceptance tests

- **Seal:** before installing bearings, soak the one-piece body for
  one hour, then 24 hours in shallow fresh water. Briefly immerse the bare
   closed body a few centimetres to test the continuous deck and mast well too.
   There are no lid seams. Compare weights
  after drying the outside consistently. Require no visible leak and no
  progressive measurable mass gain. With a 0.1 g scale, a 0.5 g gain is a clear
  rejection, not an acceptable allowance. Fix and repeat until stable.
- **Loaded flotation:** use the measured sailing mass and placement. Amas can
  touch lightly; deeply immersed amas or unexpected bow/stern immersion mean
   the load distribution differs from the model. Re-evaluate if over 350 g.
- **Bearing/clevis friction:** the complete linkage must respond freely in
  both directions without sticking, including while tilted. The model's
  0.010 N mm target corresponds to about an 0.085 g trial load at a 12 mm lever;
  an ordinary kitchen scale may not resolve that. A hand flick is not a
  measurement of starting torque.
- **Water-loaded steering:** with the rig removed, move the hull through a
  shallow test tank while applying airflow to the vane. Check correction sense
  and response with the rudder actually loaded by water. A fan-only dry test
  does not exercise the dominant hydrodynamic load.
- **First sailing:** use a shallow, calm area with a slack retrieval line and
  steady light wind. Check neutral rudder tracking first, then connect the vane.
  Record true/apparent wind if measurable, boat speed, course response and
  oscillation. Do not carry v1's asserted minimum-wind or capsize numbers into v2.

The unresolved original hardware measurements are the fork gap, usable insertion
and assembled link length. Clamp fit and grip also need a real test with your
bolts, nuts and dowels. The other outstanding evidence is physical: print quality,
water uptake, actual masses, breakaway torque and loaded steering behavior.

## Rebuilding

Open [Lahar_v2.FCStd](../cad/Lahar_v2.FCStd) to inspect the ready-built assembly.
It contains printable parts and objects labeled `Reference - do not print`.
Its generated Part solids are driven by the [macro](../cad/lahar.FCMacro), not
by an independent hand-edited drawing. Change that source and regenerate.

From the repository root, with FreeCAD's Python environment configured:

```sh
"$FREECAD_PYTHON" boats/lahar/v2/cad/export_print.py --amf-dir "$WORK"
python3 boats/lahar/v2/cad/slice_print.py \
  --slicer "$PRUSA_SLICER" --profiles "$PRUSA_PROFILES" \
  --amf-dir "$WORK" --roundtrip
"$RENDER_PYTHON" boats/lahar/v2/cad/validate.py --engineering --amf-dir "$WORK"
"$RENDER_PYTHON" boats/lahar/v2/cad/render.py --amf-dir "$WORK"
```

Install [requirements-render.txt](../cad/requirements-render.txt) in a separate
ordinary-Python environment for `RENDER_PYTHON`, which now runs both the mesh-based
flotation check and the renders. FreeCAD's Python must import
FreeCAD, Part and MeshPart; import FreeCAD before Part. Tested with FreeCAD
1.1.3, ordinary Python 3.12, and official PrusaSlicer 2.9.6.

For the current WSL setup, FreeCAD is extracted under
`/tmp/lahar-tools/freecad/squashfs-root/usr`; its `bin/python` needs `PYTHONPATH`
and `LD_LIBRARY_PATH` set to its `lib` directory for that invocation. The slicer
is `/mnt/c/Temp/lahar-tools/PrusaSlicer-2.9.6/prusa-slicer-console.exe`, and its
profile bundle is `resources/profiles/PrusaResearch.ini` under that directory.
Use a Windows-mounted working directory, such as `/mnt/c/Temp/lahar-v2-work`,
when running the Windows slicer from WSL. Temporary tools may not persist.

The exporter also writes the CAD-derived exterior meshes and parameter snapshot
used for hydrostatics to the working directory. The one-piece body, 46 closed
cells, deck-down orientation, skin thickness and steering travel are checked
before export, along with the solid vane web, clamp hardware fit, blind-guide
backing and rejection of reversed/swapped mounts. The two projects must round-trip and remain inside the actual
250 x 210 x 220 mm MK4S volume. No physical print or leak test has been performed.

Rebuilds overwrite only generated assets inside this v2 directory. Never run a
rebuild inside the frozen v1 archive. Preserve physical test observations before
changing another design parameter.

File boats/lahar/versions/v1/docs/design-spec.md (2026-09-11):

# Lahar v1 — Downwind Trimaran

Boston Bunnies Sail Team. Design specification and build guide. Companion file:
[`cad/lahar.FCMacro`](../cad/lahar.FCMacro) (run inside FreeCAD via Macro → Macros…
→ Execute; edit the PARAMETERS block and re-run to regenerate any part).

## Principal dimensions

| Item | Value |
|---|---|
| Length overall (main hull) | 200 mm |
| Beam overall | 196 mm |
| Main hull max beam × depth | 69 × 40 mm (fullest section aft of midships) |
| Ama length × beam × depth | 165 × 31 × 14.5 mm |
| Design waterline | ~16 mm below deck at 106 g |
| Design displacement (all-up weight) | ~106 g |
| Ama clearance above waterline | +1.4 mm at 106 g (+0.4 mm even at 114 g) |
| Print footprint (one-piece body) | 200 × 196 mm, 46 mm tall — fits a 220 × 220 bed |

Sized by a full end-to-end audit (mass build-up -> equilibrium waterline ->
trim -> stability -> balance). The fullest hull section sits aft of midships so
the centre of buoyancy (x=106) lands under the centre of gravity (x=111): the
boat floats with a mild +2.3 deg stern-down trim, which lightens the bow and
helps downwind tracking. If your build comes out heavier than the table below,
the amas immerse early and drag; re-run the macro with fatter `MAIN_B` values.

## Weight budget

| Component | Estimate | Print settings that matter |
|---|---|---|
| Main hull (in body) | ~42 g | 2 perimeters (0.8 mm), **4 % infill**, 4 top layers |
| Both amas (in body) | ~17 g | **0 % infill** — they are floats |
| Beams, gussets, skeg, pads (in body) | ~16 g | print as sliced |
| Mast + yards + cloth | ~10.5 g | 6 mm + 4 mm dowels, light cloth |
| Printed steering parts + stocks | ~9 g | rudder/vane/arms, 3 mm rods |
| Bearings, pushrod, screw, glue | ~11 g | 623ZZ x2, M2 rod, M3 screw |
| **All-up** | **~106 g** | |

Weigh the printed body: target ~75 g. Every extra 8 g costs ~1 mm of ama
clearance; the design still floats the amas clear at 114 g all-up.

## Sail (you build this part)

* **Rig:** square sail on a mast with two transverse yards, exactly as you planned.
* **Sail: 190 mm wide × 170 mm tall**, flat cloth (light ripstop, a plastic bag,
  or Tyvek). Lash head and foot to the yards, mast between them.
  Same area as a 160 x 200 sail but 65 mm lower in the air — see stability below.
* **Mast:** 6 mm hardwood dowel, ~250 mm long. 24 mm sits in the printed socket;
  foot yard at 40 mm above deck, head yard at 210 mm.
* **Yards:** 4 mm dowel or bamboo, ~210 mm each.
* **Mast position:** the socket is at 40 % LOA from the bow — sail effort forward,
  skeg aft, per the arrow rule.
### Stability (why the rig is short and wide)

Sail centre of effort is **125 mm above deck**; heeling lever to the centre of
lateral resistance is 135 mm. One fully buried ama gives **30 mN·m** of
righting moment (37 cm³ of buoyancy at an 82.5 mm arm).

| Apparent wind, 30° off axis | Heeling moment |
|---|---|
| 2.0 m/s | 6.4 mN·m |
| 3.0 m/s | 14.4 mN·m |
| 3.5 m/s | 19.6 mN·m |
| 4.3 m/s | **30 mN·m — capsize** |

* **Wind limit:** comfortable to ~3.3 m/s apparent; capsize at ~4.3 m/s in a
  30° gust. Note apparent wind downwind is true wind *minus* boat speed, so the
  boat is most vulnerable at the moment you let it go, before it accelerates.
* A 200 mm tall sail on a 330 mm mast (the first version of this design) put the
  CE at 190 mm and dropped the capsize threshold to ~3.5 m/s. Trading height for
  width at constant area bought 21 % more wind for free.
* **The main hull alone has negative GM** (about −9 mm): it is too slender to
  stand up by itself and will loll a degree or two until one ama takes up. That
  is normal trimaran behaviour, not a fault — the amas *are* the stability.
* **Lengthening the main hull does nothing for this.** BM_T = I_T/V, and both
  scale with length, so stretching 200 → 280 mm leaves BM_T at 10.2 mm exactly
  while adding 40 % wetted area. Heel resistance is a beam property. The amas
  were lengthened to 165 mm and their sections grown 12 % instead — 37 cm³ each,
  +58 % righting moment over the original amas, inside the same footprint.
* Widening the ama spacing would also help, but 82.5 mm already puts overall
  beam at 196 mm, near the limit of a 220 mm print bed.

## Steering gear

Layout matches the diagram from our conversation: vane pivot at x = 140 mm,
rudder stock at x = 172 mm, skeg immediately ahead of the rudder, all on centerline.

* **Bearings:** two **623ZZ (3 × 10 × 4 mm)** pressed into the deck counterbores.
  Vane spins in one; rudder stock runs through the other plus a plain hole where
  it exits the hull bottom.
* **Stocks:** 3 mm carbon rod (best, waterproof) or bamboo skewer, ~70 mm for the
  rudder, ~60 mm for the vane. Push-fit into the printed sockets; a drop of CA if loose.
* **Vane paddle:** blade faces **forward** (downwind of the axis when running).
  Blade is 36 x 72 x 1.0 mm — deliberately thin, because blade mass is the whole
  balance problem. A 50 mm counterweight arm sits aft at the blade's vertical
  centroid (z = 62), so it trims both the yaw moment and the tipping couple on
  the bearing.
* **Balancing (do not skip):** blade moment is ~67 g.mm, arm gives back ~35 g.mm,
  leaving ~33 g.mm. An **M3 x 16 screw + nut (~1.2 g) at ~28 mm** along the slot
  cancels it. Slide the screw until the paddle sits indifferent at every angle
  with the boat tipped 10-15 deg, then lock the nut.
  Why it matters: the axis is vertical, so gravity makes no yaw torque when level
  — but at 5 deg of heel a 96 g.mm imbalance produces 0.085 N.mm, against only
  0.037 N.mm of aerodynamic torque at 1 m/s apparent wind and 10 deg of error.
  An unbalanced vane steers to the low side, not to the wind.
* **Linkage:** M2 RC threaded pushrod with a clevis at each end — your variable-
  length calibration rod. **Vane arm points to PORT, tiller arm to STARBOARD.**
  Opposite sides is mandatory: it reverses the sense so the rudder pushes the bow
  back. Same side and the boat spirals; if that happens, flip one arm.
* **Gain** = vane-hole radius ÷ tiller-hole radius. Holes at 6/10/14/18 mm (vane)
  and 12/18/24/30 mm (tiller). **Start at 6/18 ≈ 0.33.** Fishtailing → smaller
  ratio; lazy wandering → larger.

## Printing

For pre-sliced CORE One+ / stock 0.4 mm high-flow nozzle / PLA / smooth PEI jobs,
see the [USB printing instructions](../instructions.md). These preserve the
low-infill design but have not been physically printed. PrusaSlicer reports
"Floating bridge anchors" inside the body; successful bridging and watertightness
remain to be tested. The current measured mesh footprint is 200 x 197.29 mm,
slightly wider than the nominal station-based figure because of loft interpolation.

* **Body:** flip 180° about X in the slicer so the deck is on the bed. Beams then
  lie flat on the bed, all sockets print as simple recesses, no supports. Use
  0.12–0.16 mm layers for the last 5 mm of the hull crowns (the rounded bottoms
  close like a dome). 2 perimeters; **4 % infill in the main hull, 0 % in the amas** — the weight
  budget and ama clearance depend on these — 4 top layers for water-tightness.
* **Rudder blade & vane paddle:** print lying flat on their sides, with supports
  beneath surfaces lifted off the bed by their thicker bosses/spines. The supplied
  steering project enables automatic snug supports from the build plate.
* **Arms:** print flat as oriented.
* PLA is fine for pond duty; seal the hull with a light acrylic spray if it seeps.

## Bill of materials

| Qty | Item |
|---|---|
| 2 | 623ZZ bearing, 3 × 10 × 4 mm |
| 1 | 6 mm hardwood dowel, ≥ 260 mm (mast, cut to 250) |
| 2 | 4 mm dowel/bamboo, 210 mm (yards) |
| 1 | 3 mm carbon rod or skewers, ≥ 150 mm total (stocks) |
| 1 | M2 RC pushrod + 2 clevises (adjustable link) |
| 1 | M3 × 16 screw + 2–4 nuts (vane counterweight) |
| — | Light sail cloth ~210 × 190 mm (finished sail 190 × 170), thread, CA glue |

## First-sail checklist

1. Float the bare body: waterline ~16 mm below deck, amas just clear, and a
   *slight stern-down attitude is correct* — the design puts LCG a few mm aft
   of LCB on purpose. Trim with coins only if the bow digs or the stern is awash.
2. Fit rudder only, lock it centered, sail without the vane: the skeg should give
   one gentle swing back after a nudge. Two or more overshoots → sand the skeg smaller.
3. Add the vane at gain 0.33, dead-downwind setting (arm neutral when the paddle
   points at the bow). Nudge the bow off course by hand: rudder must deflect to
   bring it back. Wrong way → swap an arm to the other side.
4. Lengthen/shorten the pushrod so the rudder is exactly centered when the vane
   is aligned — that screw adjustment is your trim tab.

## Design history (from the conversation, 25 Aug 2026)

Sideways drift traced to coincident centers of effort and lateral resistance →
fixed with the arrow rule (effort forward, resistance aft). Skeg sized against
overshoot/fishtailing. Cross-sail rejected (destabilizing vane, cos-flat gains);
keel rejected downwind (ballast useful, lateral area harmful). Trimaran chosen
over mono/cat/proa: amas need no precision because they carry no load. Amas
double-ended — transoms only pay above Froude ≈ 0.5, far beyond this scale — and
finless: all lateral resistance lives in one centerline skeg. Vane gear per
classic model-yacht practice: needle-supported vane upwind of the sail, short
vane arm / long tiller arm (gain = Lv/Lt — corrected from an earlier statement),
arms on opposite sides. Upwind conversion deferred; would need cambered sail,
daggerboard forward, and reversed CE/CLR order.

## End-to-end audit summary (25 Aug 2026)

Computed, not assumed: all-up 106 g floats at 15.9 mm freeboard with +1.4 mm ama
clearance (robust −8/+8 g). Trim +2.3 deg stern-down (LCB 106 / LCG 111). Sail
CE at x=80 vs CLR at x=122: 21 % LOA separation — arrow-rule stable. Capsize at
4.3 m/s apparent (30 deg gust), comfortable to ~3.3 m/s. Expected boat speed
0.5–0.7 m/s (Fr ≈ 0.45–0.5, wave-drag limited), so apparent wind ≈ true − 0.6.
Vane torque at 1 m/s apparent and 10 deg error is ~0.037 N·mm vs ~0.003 N·mm of
friction + residual-imbalance losses: authority margin >10x once the boat has
any breeze; below ~0.7 m/s apparent the vane will wander — that is physics, not
a defect. Geometry cleared: socket floors ≥ 14 mm, bearing pads ≥ 31 mm wide,
skeg embeds 25 mm into the hull, body 200 × 196 × 46 mm on a 220 × 220 bed.
Corrections made during audit: weight budget raised 95 → 106 g (original was
optimistic), main hull widened and its volume shifted aft to cure a 5.7 deg
stern squat, amas re-proportioned wider/shallower, skeg and rudder deepened to
keep grip under the deeper hull.

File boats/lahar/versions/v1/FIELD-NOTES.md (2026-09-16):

# Lahar v1 field observations

Recorded 2026-09-15, when v2 was requested. Original files in this directory
are preserved unchanged; this note updates their historical status.

## What was built

The 200 mm downwind trimaran, approximately 196-197 mm beam, with a nominal
106 g design target, 190 x 170 mm square sail, two 623ZZ bearings and an M2
clevis/pushrod linkage. The owner has physically printed v1. Its original
CORE One+ slicer jobs and all design assets are retained here.

## Owner observations

- The boat takes in water while floating. The specific entry path and leak
  rate were not measured or isolated.
- There is insufficient clearance behind the skeg for the rotating rudder,
  especially the cylindrical boss.
- The printed arms are too thick for the MECCANIXITY metal clevises, and the
  pivot holes are too small for their screws.
- The owner reports substantial apparent friction and doubts downwind steering
  authority. No measured breakaway torque or loaded steering response was supplied.
- Existing materials include the two bearings, 6 mm hardwood dowel, 3 mm carbon
  rod, 4 mm dowel, MECCANIXITY M2 45 mm rod and metal clevises.

## Why v2 changes these parts

v1's macro requests 4 mm arm thickness and 1.6 mm holes. Its rudder axis and
skeg trailing edge are both at X=172, putting the 8 mm boss in the skeg region.
Its print notes already warn about unvalidated watertightness and floating
bridge anchors. The shaft passage through the hull is another potential water
path, not a proven explanation of the owner's particular leak.

v2 uses inspectable thicker open shells with bonded lids, removes the wet shaft
penetration, checks full rudder sweep clearance, adapts the tabs and screw holes,
and uses a larger light-film vane with a less oblique linkage and better bearing
clearances. It also increases displacement and recomputes trim for the extra
weight. Its files are for the owner's confirmed MK4S, not the CORE One+.

The [v2 design guide](../../v2/docs/design-spec.md) records the remaining physical
tests. v1's asserted light-wind authority and capsize numbers are not physical
measurements and must not be carried forward as established performance.

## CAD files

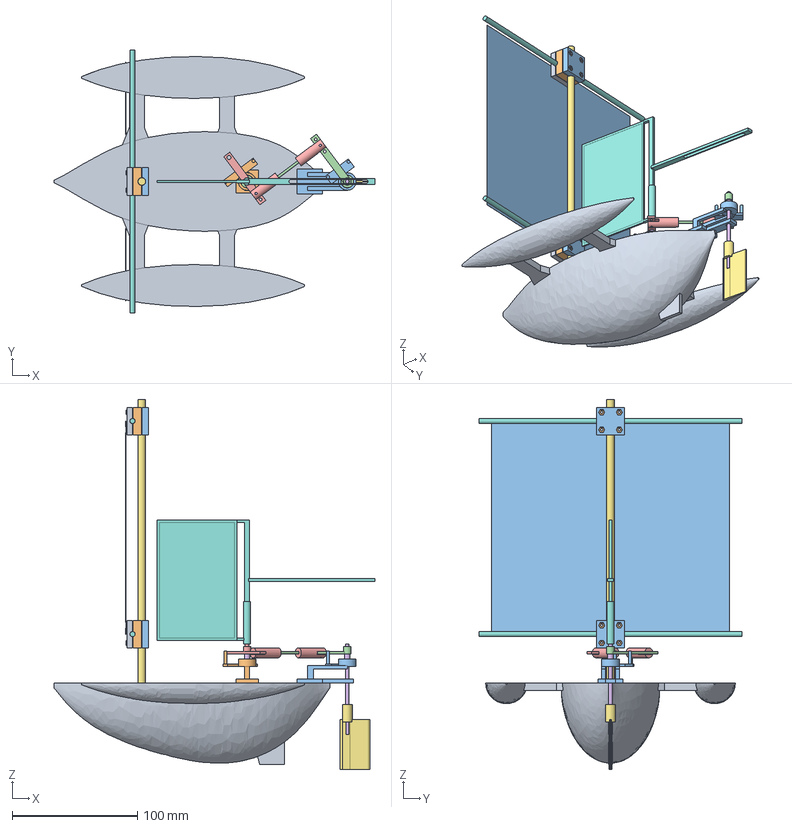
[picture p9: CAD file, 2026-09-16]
boats/lahar/v2/cad/Lahar_v2.step
256.0 x 210.0 x 295.2 mm

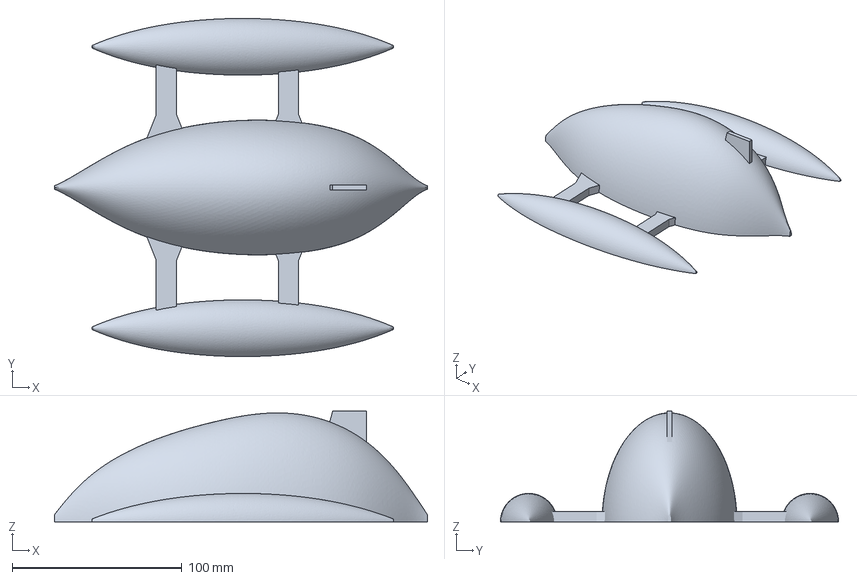
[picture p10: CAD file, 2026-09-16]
boats/lahar/v2/print/projects/Lahar_v2_Body_MK4S_PLA_04.3mf
220.0 x 199.4 x 65.2 mm

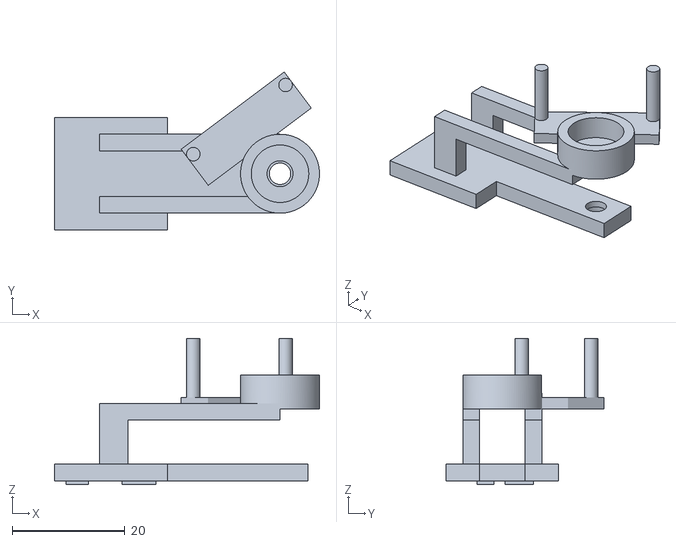
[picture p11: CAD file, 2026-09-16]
boats/lahar/v2/print/stl/Rudder_Stand.stl
47.0 x 28.1 x 25.9

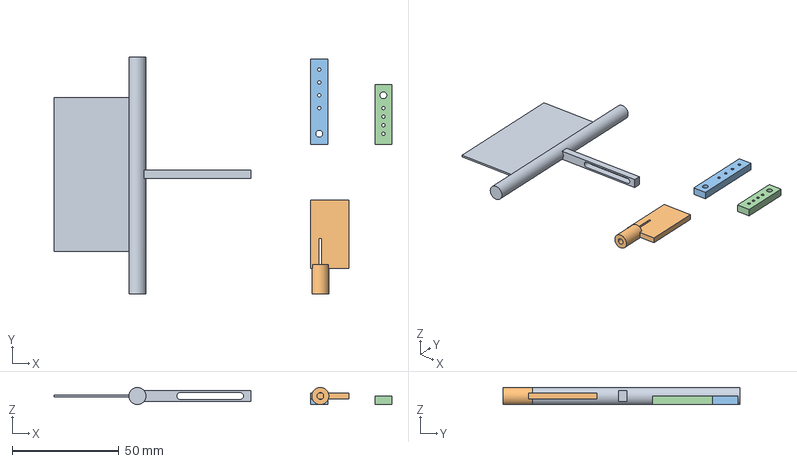
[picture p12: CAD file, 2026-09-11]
boats/lahar/versions/v1/print/projects/Lahar_Steering_COREONEplus_PLA_04.3mf
158.0 x 111.0 x 8.00 mm
Vane_Paddle
Rudder_Blade
Rudder_Tiller
Vane_Arm

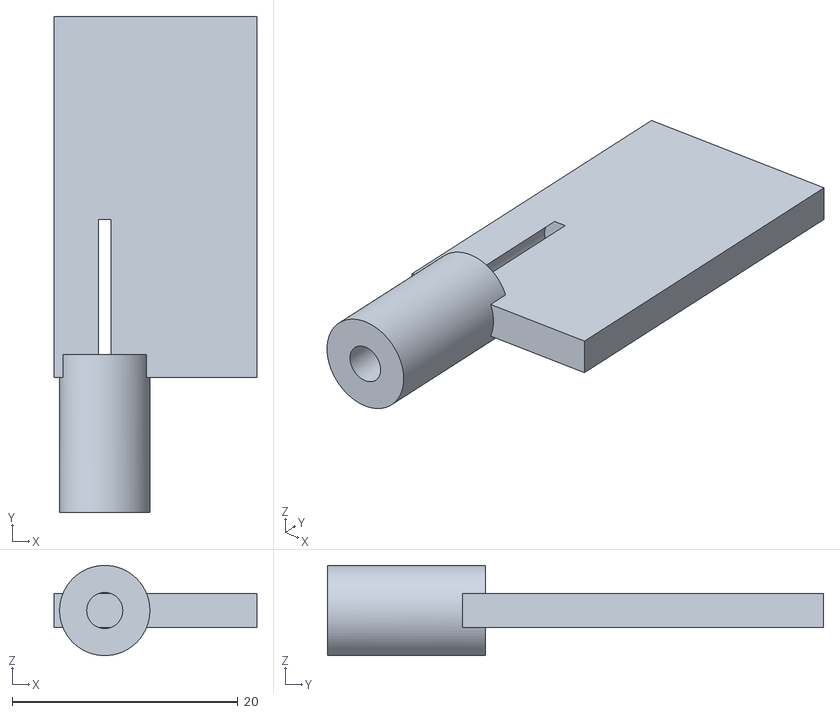
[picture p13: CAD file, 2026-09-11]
boats/lahar/versions/v1/print/stl/Rudder_Blade.stl
18.0 x 44.0 x 8.00

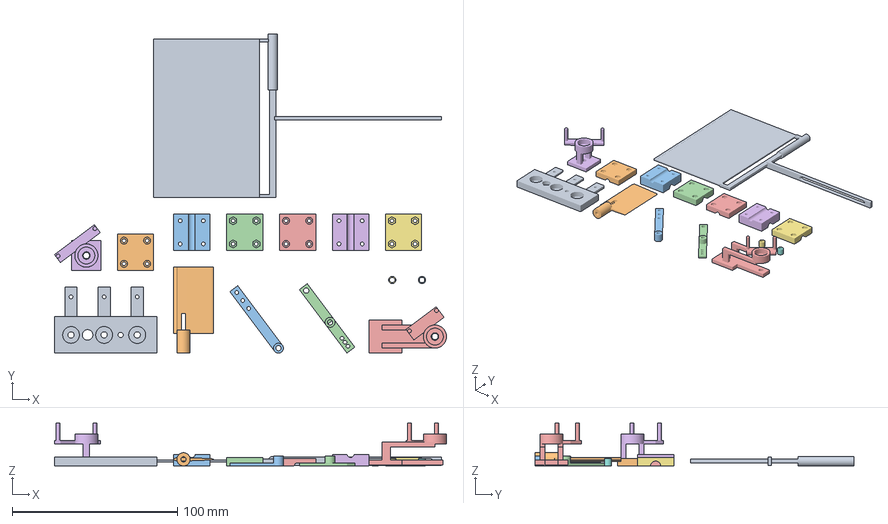
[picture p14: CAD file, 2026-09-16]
boats/lahar/v2/print/projects/Lahar_v2_Steering_MK4S_PLA_04.3mf
237.0 x 193.0 x 25.9 mm
Hardware_Fit_Coupon
Rudder_Blade
Rudder_Tiller
Vane_Arm
Rudder_Stand
Vane_Stand
Vane_Spacer
Rudder_Spacer
Vane_Frame
Lower_Yard_Yard_Cap
Lower_Yard_Saddle
Lower_Yard_Mast_Cap
Upper_Yard_Yard_Cap
Upper_Yard_Saddle
Upper_Yard_Mast_Cap

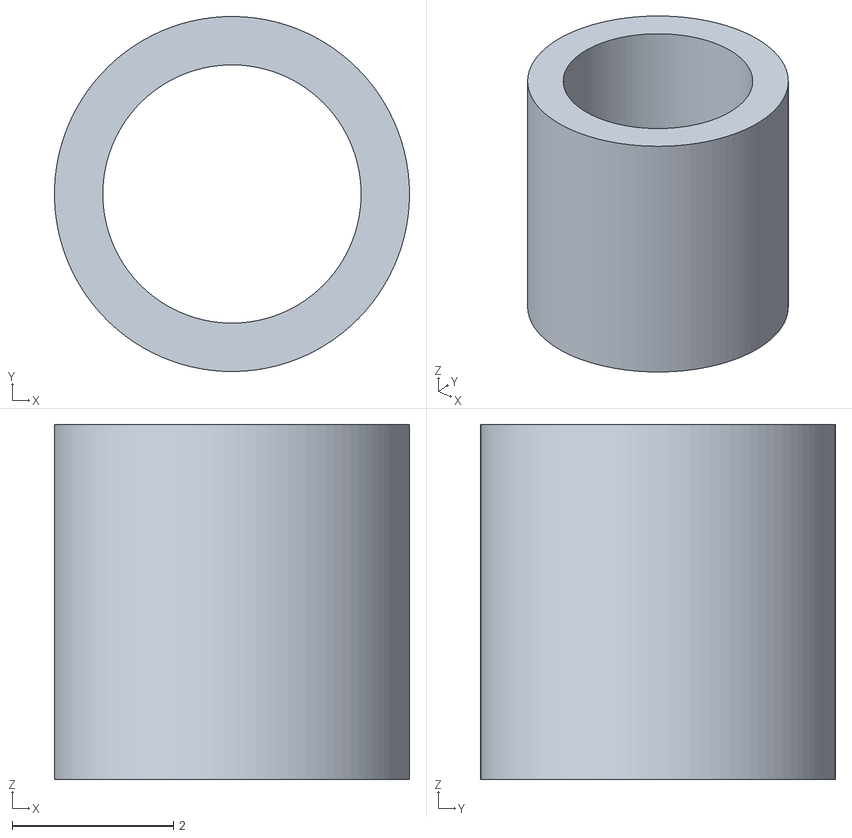
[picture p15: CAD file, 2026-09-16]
boats/lahar/v2/print/stl/Rudder_Spacer.stl
4.40 x 4.40 x 4.40

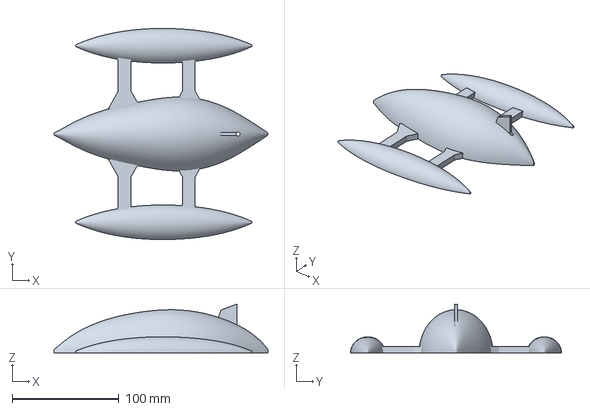
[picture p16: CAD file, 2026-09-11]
boats/lahar/versions/v1/print/projects/Lahar_Body_COREONEplus_PLA_04.3mf
200.0 x 197.3 x 45.6 mm

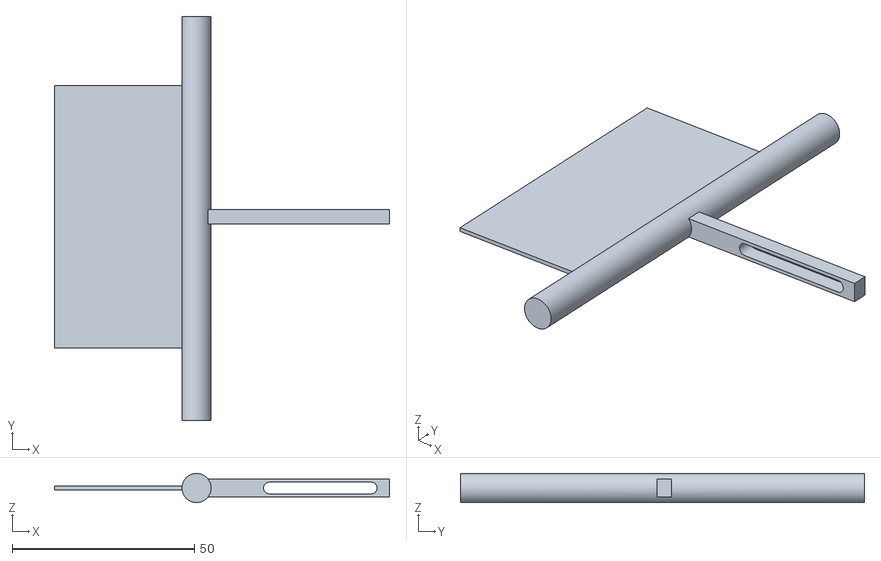
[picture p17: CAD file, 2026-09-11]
boats/lahar/versions/v1/print/stl/Vane_Paddle.stl
92.0 x 111.0 x 8.00

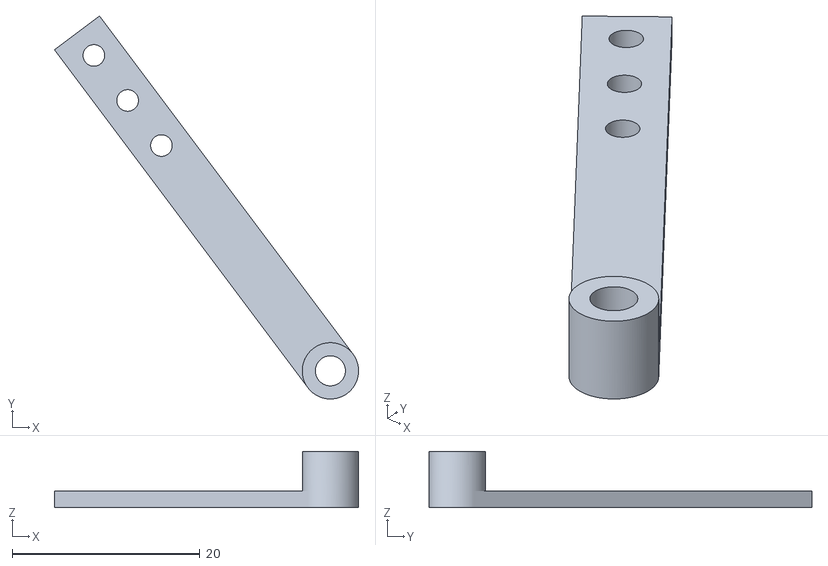
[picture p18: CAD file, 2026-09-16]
boats/lahar/v2/print/stl/Rudder_Tiller.stl
32.4 x 40.8 x 6.00

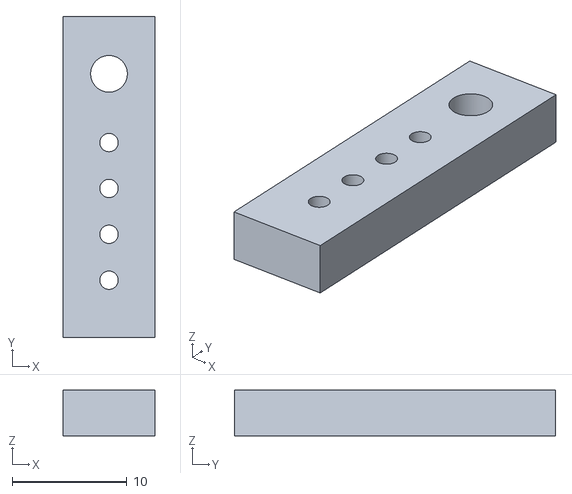
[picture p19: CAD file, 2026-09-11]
boats/lahar/versions/v1/print/stl/Vane_Arm.stl
8.00 x 28.0 x 4.00

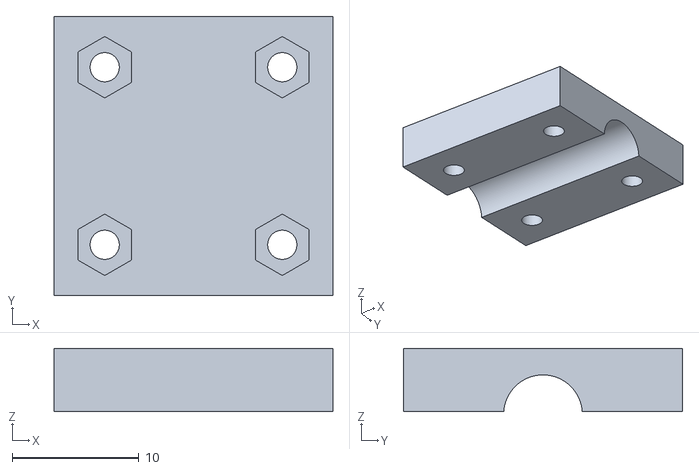
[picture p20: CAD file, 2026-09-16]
boats/lahar/v2/print/stl/Upper_Yard_Mast_Cap.stl
22.0 x 22.0 x 5.00

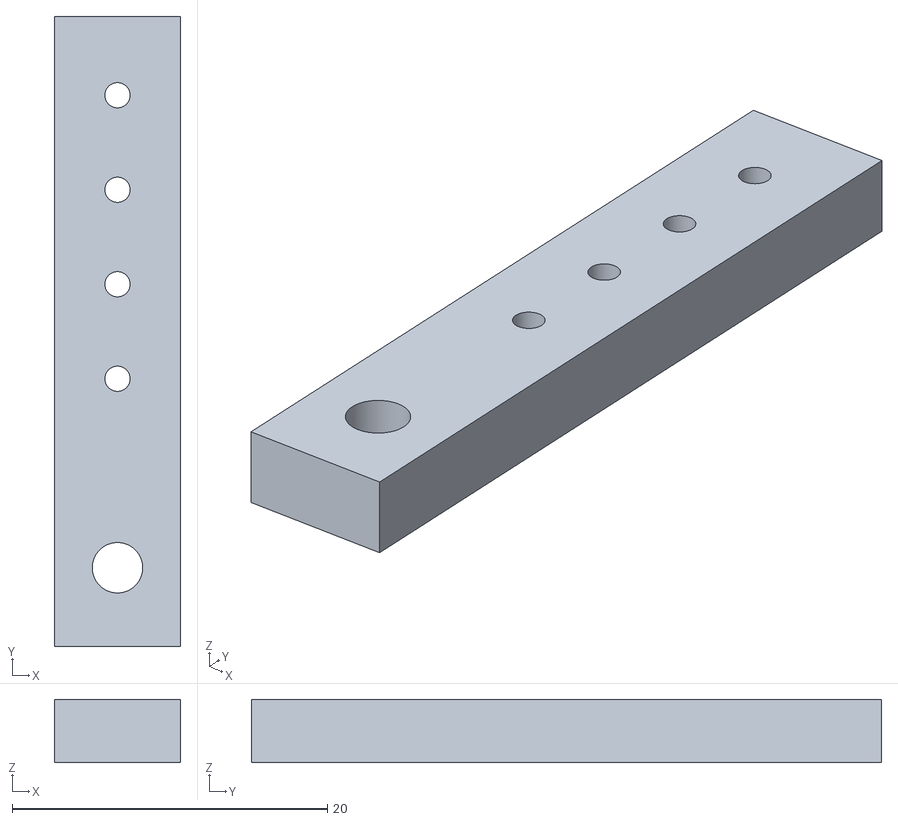
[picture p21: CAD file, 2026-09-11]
boats/lahar/versions/v1/print/stl/Rudder_Tiller.stl
8.00 x 40.0 x 4.00

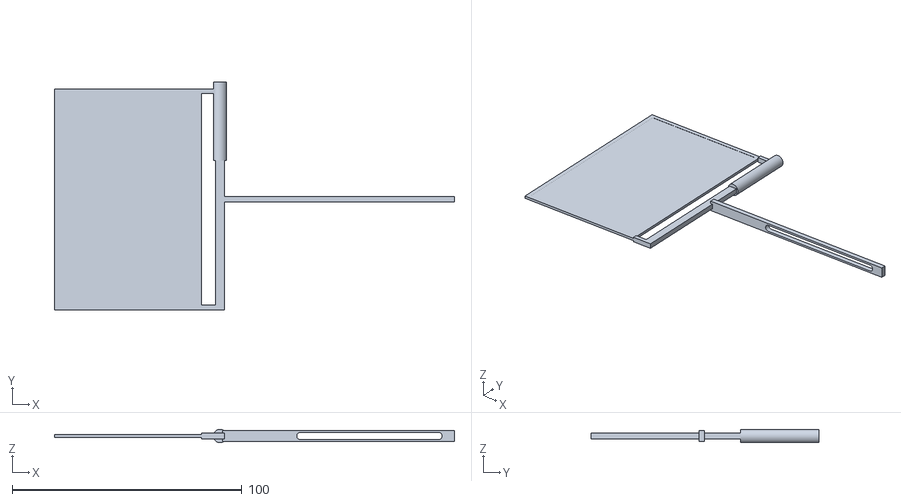
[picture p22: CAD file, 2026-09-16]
boats/lahar/v2/print/stl/Vane_Frame.stl
174.0 x 99.0 x 5.80

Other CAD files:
boats/lahar/versions/v1/print/stl/Trimaran_Body.stl
boats/lahar/v2/print/stl/Lower_Yard_Mast_Cap.stl
boats/lahar/v2/print/stl/Trimaran_Body.stl
boats/lahar/v2/print/stl/Upper_Yard_Saddle.stl
boats/lahar/v2/cad/Lahar_v2.FCStd
boats/lahar/v2/print/stl/Hardware_Fit_Coupon.stl
boats/lahar/v2/print/stl/Lower_Yard_Saddle.stl
boats/lahar/v2/print/stl/Lower_Yard_Yard_Cap.stl
boats/lahar/v2/print/stl/Rudder_Blade.stl
boats/lahar/v2/print/stl/Upper_Yard_Yard_Cap.stl
boats/lahar/v2/print/stl/Vane_Arm.stl
boats/lahar/v2/print/stl/Vane_Stand.stl

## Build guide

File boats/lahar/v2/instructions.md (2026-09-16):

# Printing Lahar v2 on the Prusa MK4S

These files are for the setup confirmed on 2026-09-15: **Original Prusa MK4S,
stock 0.4 mm high-flow nozzle, ordinary 1.75 mm PLA, smooth PEI, no MMU**.
Other nozzles, materials, printer models, or an MMU require re-slicing.

**Prototype status:** CAD, meshes, slicing, and project re-slicing have been
checked. The actual print, hardware fit, seal, and sailing behavior have not.
Start with the combined steering, clamps and coupon job. Do not interpret a successful slice as proof of
watertightness or steering performance.

**Use the one-piece revision below.** It replaces the earlier separate-hull/lid
v2 draft. There is now one body job, with the deck flat on the bed and rounded
bottoms upward. The amas, crossbeams and skeg are part of that same print.
The latest body has recessed steering-mount keys; its matching stands have feet.
All 16 parts now fit in **two jobs**. The steering job includes the solid vane,
both four-bolt yard-clamp sets and the fit coupon. Only placement and job grouping
changed; no part was resized or omitted. The standalone coupon job is no longer needed.
Do not mix the updated keyed stands with an earlier unkeyed v2 body.

## USB files

Print the steering job first, check the hardware fits, then print the body.
Print each job once, clearing the sheet between jobs:

| File | Contents | Normal-mode estimate | PLA including waste |
| --- | --- | --- | --- |
| [Lahar_v2_Steering_MK4S_PLA_04.gcode](print/usb/Lahar_v2_Steering_MK4S_PLA_04.gcode) | Fifteen parts: eight steering parts, six clamp pieces and the fit coupon | 6 h 4 min 48 s | 58.03 g |
| [Lahar_v2_Body_MK4S_PLA_04.gcode](print/usb/Lahar_v2_Body_MK4S_PLA_04.gcode) | Enclosed main hull, two amas, beams, skeg and steering-mount recesses, all deck-down | 26 h 3 min 12 s | 238.82 g |

Total: **32 h 8 min, 296.85 g**, including the coupon, supports and brims.
Have at least 350 g available to allow for loading and a repeat fit test.
These are ordinary text G-code files, not binary BGCODE. They have no thumbnail.

Use a working FAT32 USB drive. Copy the two linked G-code files to it, safely
eject, and insert it into the MK4S. Do not rename an STL or 3MF to G-code.
Do not reformat a working drive; formatting erases its contents.

## Fit check before the body

The coupon now shares the steering bed with all the other small parts. After
that job finishes, remove the parts, clear the sheet and use the coupon and
actual printed clamps to check fit before committing to the long body print.

Hold the coupon with the three projecting tongues pointing away from you.
From left to right, their thicknesses are **1.5, 1.8, 2.1 mm**; all have a
**2.3 mm pivot hole**. Behind those tongues, the bearing recess diameters are
**10.1, 10.2, 10.3 mm**, respectively. The larger hole between the first two
bearing recesses is the **6.4 mm mast gauge**; the smaller hole between the
second and third is the **3.2 mm stock-socket gauge**.

1. Remove the brim and small burrs without changing the test surfaces.
2. Try your clevis on the middle, 1.8 mm tongue. Its M2 pivot screw must pass
   freely, and the joint must rotate without squeezing the plastic between
   the cheeks. Check clearance after the screw is securely retained.
3. Try a 623ZZ bearing in the middle, 10.2 mm recess. It must seat without
   force that distorts the outer race. Try the neighboring diameters to learn
   which fit your printer produces. Never hammer a bearing into place.
4. Test the 6 mm mast and 3 mm carbon stock. Also slide the carbon stock through
   the real bearing before assembly; a printed gauge cannot certify that fit.
5. If the middle sizes do not work after removing burrs, stop before the body
   job. Change `TAB_THICKNESS`, `PIN_DIAMETER`, `BEARING_OD`, `MAST_DIAMETER`, or
   `STOCK_SOCKET` in the [macro](cad/lahar.FCMacro), then rebuild the affected files.
   Do not scale the entire boat to fix a hole.

The manufacturer's image gives the clevis's **8 mm outside width**, not its
inside gap. The middle tongue is a proposed fit, not a manufacturer-certified
dimension. The [design guide](docs/design-spec.md#clevis-and-pushrod) records
the verified and unknown dimensions.

The coupon checks the original rod sockets and clevis interface, not the new
clamp grooves, nut pockets or locating feet. Dry-fit the printed clamps with
your actual **eight M2 x 16 socket-cap bolts and eight standard M2 hex nuts**
before installing the sail. The clamp grooves are 6.2 and 4.2 mm, with split
gaps for tightening around nominal 6 and 4 mm dowels.

## Prepare and print

1. Complete the MK4S self-test and calibration, and confirm a normal Prusa test
   print works. Use current stable firmware from Prusa. Check that the physical
   nozzle is the stock 0.4 mm high-flow type.
2. With the machine cool, remove old prints and debris. Clean the smooth PEI
   sheet with plain 90%+ isopropyl alcohol and a clean paper towel; wash persistent
   grease off the removed sheet with dish soap and water, rinse, and dry.
3. Load ordinary PLA through the printer's filament-loading menu. These jobs use
   **230 C first layer, 225 C subsequent layers, and a 60 C bed**. Check the
   filament manufacturer's range; unsuitable PLA needs its own profile.
4. Select the appropriate file in **Print**. Keep all printer, nozzle and
   firmware compatibility checks enabled. Never dismiss a mismatch warning.
5. Let the printer finish its normal preheat, homing, nozzle cleaning, mesh
   probing and purge sequence. The temporary low nozzle temperature is intentional.
6. Watch the entire first layer. Stop if extrusion is intermittent, lines do
   not bond, a part lifts, or plastic accumulates on the nozzle. Wait for the
   machine to cool before reaching in or removing the sheet.
7. Check long jobs periodically. The body prints **deck-down, rounded bottoms
   upward**, like v1. Its 220 x 199.4 mm footprint, including the attached amas,
   fits the MK4S's 250 x 210 mm bed with the supplied brim. No removable support
   belongs inside the hulls; the modeled ribs and sloped roofs remain in the boat.
8. Let each completed job cool. Flex the sheet gently. Remove steering supports
   carefully, especially beneath the solid vane, mounting feet, clamp grooves,
   short stock guides, bearing shoulders and rudder socket. Do not lever against
   the 1 mm vane web or its counterweight arm. Clear supports from all four bolt
   passages and the captive nut pockets on each clamp set.
9. Support the cooled body under its hulls while releasing it; do not pull on
   an ama or the skeg. Check the outer walls, deck and rounded closures for
   voids, then weigh the cleaned parts and soak-test the body before adding the rig.

The [assembly-detail image](renders/assembly-details.png) and
[yard-clamp instructions](docs/design-spec.md#yard-clamps) identify the clamp
pieces. Print this job once: it already contains both complete sets. Metal
bolts and nuts are not printed. The [mount guide](docs/design-spec.md#steering-mount-guides)
shows where each stand belongs; dry-fit its feet in the shallow recesses and
then glue its base to the deck. Do not drill or deepen those recesses.

The MK4S is a bed-slinger, not a CORE One+ with chamber ventilation. Leave room
for bed motion. If it is inside a separate enclosure, follow Prusa's PLA
ventilation guidance; do not apply CORE One+ door/grille instructions to it.

## What is and is not the same as v1

| Setting | v1 | v2 |
| --- | --- | --- |
| Printer | CORE One / One+ HF0.4 | Original Prusa MK4S HF0.4 |
| Body construction / orientation | Integrated closed body, deck-down | Integrated closed body, deck-down |
| Layers / first layer | 0.15 / 0.20 mm | 0.15 / 0.20 mm |
| Perimeters | 2 | 4, 0.45 mm requested width |
| Top / bottom solid layers | 4 / 4 | Body 12 / 12; steering and coupon 8 / 12 |
| Hull cavities | Slicer infill: main 4%, amas 0% | 46 explicit enclosed CAD cells with 45-degree internal roofs |
| Infill in actual modeled plastic | Low-density body | 100% rectilinear; the hull cavities remain empty |
| Hull supports | Off, internal bridge warning | Off, no slicing warnings |
| Steering supports | Automatic snug | Automatic snug, build-plate only, 0.20 mm contact gap |
| Brim setting | 3 mm | 3 mm; actual brim extent depends on first-layer footprint |
| Perimeter / external speed | 60 / 40 mm/s | 40 / 25 mm/s |

The official presets are `0.15mm STRUCTURAL @MK4S 0.4`,
`Generic PLA @MK4S HF0.4`, and `Original Prusa MK4S HF0.4 nozzle`, from
PrusaSlicer 2.9.6. Startup and shutdown commands come from that printer preset,
not from the old CORE One+ files. Every project has a full resolved configuration.
The body uses the classic perimeter generator with thin-wall detection and
180-degree bridge direction. These settings were checked on the actual ribs
and final roof closures; changing them requires another preview and test.

## Inspect or re-slice

Open these **as projects**, not as imported geometry:

- [Steering, clamps and coupon project](print/projects/Lahar_v2_Steering_MK4S_PLA_04.3mf)
- [Body project](print/projects/Lahar_v2_Body_MK4S_PLA_04.3mf)

Use Preview to inspect the continuous first-layer deck and beams, rounded outer
walls, internal ribs and sloped closures, blind mast well and guide recesses,
solid vane web, thin tongues, clamp grooves and steering supports. The [STLs](print/stl/) are already
in millimetres and print-oriented. Do not flip them again.

The [assembly guide](docs/design-spec.md#rebuilding) includes rebuild commands.
Changing a 3MF or the macro does not update an existing G-code file.

## Checks performed

FreeCAD 1.1.3 and official PrusaSlicer 2.9.6 were used. All 16 meshes are closed
and manifold; printable CAD parts are valid single solids. The saved FreeCAD
document was reopened successfully. The body has one connected exterior and
46 closed internal cells. Both supplied slices completed without warnings;
the combined steering job has 14,716 actual support extrusion moves. Model extrusion paths fit
the MK4S's 250 x 210 x 220 mm volume. Each self-contained 3MF was re-sliced alone
and reproduced identical extrusion toolpaths and resolved settings.
All 16 parts appear exactly once across the two projects. The coupon remains
excluded from the assembled boat's weight even though it now shares a print job.
CAD checks also verify the solid vane web, nominal bolt/nut/dowel fit, all
eight clamp bolts, backed guide pockets, and rejection of reversed or swapped
steering stands. These remain nominal dimensions until checked on the real print.

None of those checks establishes real layer bonding, clevis fit, bearing
friction, watertightness or steering under water load. Those remain the
prototype's [acceptance tests](docs/design-spec.md#acceptance-tests).

## References

- [Official MK4S support, firmware, handbook and slicer](https://help.prusa3d.com/product/mk4s)
- [Prusa USB guidance](https://help.prusa3d.com/article/sd-cards-and-usb-drives_112291)
- [Prusa PLA guidance](https://help.prusa3d.com/article/pla_2062)
- [Prusa watertight-printing discussion](https://blog.prusa3d.com/watertight-3d-printing-part-2_53638/)

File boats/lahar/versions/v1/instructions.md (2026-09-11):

# Printing Lahar on a Prusa CORE One+

## Read this first

These files were prepared for the setup you confirmed: **Prusa CORE One+,
stock 0.4 mm high-flow nozzle, ordinary 1.75 mm PLA, and a smooth PEI sheet**.
They are single-material jobs, without an MMU. Do not use them unchanged on a
different printer, nozzle, or material, including PETG, silk PLA, or foaming PLA.

**Status: generated and checked in software, not physically test-printed.**
PrusaSlicer reports **"Floating bridge anchors" for the body**. Its hollow
interior and beam/float transitions include unsupported bridges. The supplied
body job preserves the design's no-support, low-infill approach, but successful
bridging and watertightness are not established. Treat it as an experimental
first print. Check the body project in PrusaSlicer Preview before printing;
do not assume that a valid mesh or completed slicing guarantees success.
The steering job has automatic, removable supports and no slicing warnings.

The sail, mast, rods, bearings, and linkage are not part of these print jobs.
See the [assembly guide and bill of materials](docs/design-spec.md).

## Files to put on the thumb drive

Copy these **two G-code files** from [print/usb](print/usb/) onto the USB drive:

| File | What it prints | Estimated time | PLA consumed |
| --- | --- | --- | --- |
| [Lahar_Body_COREONEplus_PLA_04.gcode](print/usb/Lahar_Body_COREONEplus_PLA_04.gcode) | Main hull, two side floats, beams, and skeg as one piece | 4 h 27 min | 62.0 g |
| [Lahar_Steering_COREONEplus_PLA_04.gcode](print/usb/Lahar_Steering_COREONEplus_PLA_04.gcode) | Rudder blade, tiller, vane paddle, and vane arm | 1 h 20 min | 16.5 g |

Print each file **once**, clearing the sheet between jobs. Times are slicer
estimates in normal mode, not guarantees. Consumption includes brim/support
waste; it is not the assembled boat's weight. Have at least 100 g of usable
PLA available for the two jobs. The files occupy about 20 MB combined.

The CORE One+ reads these plain-text `.gcode` files directly. No computer,
Wi-Fi, Prusa Connect account, or additional slicing is needed at the printer
once they are on the drive. Binary `.bgcode` is also supported by current
firmware, but these files do not use it. **Do not rename an STL or 3MF to G-code.**
STLs describe shapes; 3MF projects are for the slicer, not the printer's Print menu.

## Prepare the USB drive

1. Use the USB drive supplied with the printer, or a reliable USB flash drive
   formatted as **FAT32 with an MBR partition scheme**. An 8-16 GB drive is ample.
   Avoid exFAT and NTFS.
2. Connect it to your computer. If it already works with the printer, do not
   reformat it. If formatting is necessary, back up its contents and double-check
   the selected drive: formatting erases it.
3. Copy the two linked G-code files to the drive's top-level folder. Keep their
   names unchanged. You may also keep this guide on the drive for reading on a
   computer; the printer will not display Markdown instructions.
4. Wait for copying to finish, then safely eject the drive from the computer.

## Prepare the printer

1. Place the printer on a stable surface in a ventilated space. Keep its vents
   clear and keep children, pets, and loose items away from moving and hot parts.
2. Switch on the printer. For a new or newly assembled machine, complete Prusa's
   setup/self-test and calibration wizard first. Print the supplied Prusa test
   keychain successfully before making Lahar your first long job.
3. Check that the configured nozzle is the **0.4 mm high-flow nozzle** and that
   the physical nozzle matches. These files retain Prusa's printer, nozzle,
   firmware-feature, and G-code compatibility checks. Do not bypass a mismatch
   warning. Check firmware under **Info > Version info**; use current stable
   CORE One+ firmware from Prusa if an update is needed.
4. With the bed cool, remove old prints, purge lines, and debris. Make sure the
   underside of the sheet and the heatbed are clean. Seat the smooth PEI sheet
   against the rear locating pins and lay it flat. Never print on the bare heatbed.
5. Degrease the cool sheet with plain **90% or stronger isopropyl alcohol** and a
   clean paper towel. Let it evaporate before heating. Do not use hand sanitizer
   or touch the printing area afterward. PLA on clean smooth PEI normally needs
   no glue. Wash persistent grease off the removed sheet with dish soap and water,
   rinse, and dry completely before replacing it.
6. Close the door for printing. On the **CORE One+**, the printer automatically
   opens the top ventilation grille for PLA and manages the chamber fans. Keep
   that grille unobstructed; do not force it during movement. This differs from
   instructions for the original CORE One's manually operated vent.

Never put your hands inside while the printer is moving. The nozzle and bed
remain hot after a print or an abort; wait for them to cool before handling parts.

## Load PLA

1. If a different material is already loaded, select **Filament > Unload
   Filament** and follow the screen prompts. Do not pull cold filament out by force.
2. Put the PLA spool on the holder and check that it unwinds freely without a
   crossed strand. Cut the filament end to a point.
3. Feed it through the filament inlet/PTFE tube toward the Nextruder. With the
   filament sensor enabled, reaching the sensor starts loading automatically.
   Select **PLA** in the preheat prompt and wait for heating and feeding.
4. Check that filament actually emerges from the nozzle. Confirm **YES** when
   the color is correct, or **PURGE MORE** until it is. If nothing comes out,
   use **RETRY** and troubleshoot loading before printing. Remove purge waste
   only when the head is stationary, with a suitable tool; do not touch the nozzle.
5. Confirm that the screen shows PLA loaded. The supplied jobs use **230 C for
   the first layer, 225 C afterward, and a 60 C bed**, from Prusa's Generic PLA
   high-flow preset. The chamber setting is 20 C for ventilation control, not a
   request to preheat a hot enclosure. Check your spool's temperature guidance;
   if these temperatures are unsuitable, re-slice with its proper PLA profile.

## Start a print from the drive

1. Insert the USB drive into the printer's USB-A port. Leave it inserted for the
   entire job. No computer needs to remain connected.
2. Open **Print** on the LCD. Turn the knob to select the desired Lahar file and
   press it to confirm; the touchscreen can also be used where supported.
   The shorter steering job is a useful first check before committing to the body.
3. Check the filename, loaded material, and compatibility prompts. These files
   have no embedded thumbnail, so a missing picture is normal. Confirm **Print**
   to start. Menu wording can vary slightly with firmware.
4. Allow the automatic startup sequence to finish: preheating, homing, nozzle
   cleaning/probing, mesh bed leveling, final heating, and the purge line.
   The initial nozzle temperature around 170 C is intentional, not the final
   printing temperature. Do not move the sheet or touch the nozzle during probing.
5. Watch the entire first layer. The body prints **deck-down**, with all three
   hulls and connecting beams on the sheet. The steering job includes supports
   beneath the rudder and vane, plus the two flat arms. Lines should adhere
   continuously without peeling, dragging, or gathering around the nozzle.
6. If an object lifts, filament accumulates on the nozzle, or layers become loose
   strands, choose **Stop print** and confirm. Let everything cool, remove the
   failed print, clean the sheet, and correct the cause before restarting. Do not
   continue a detached print or reach in to push it back down.
7. Check progress periodically. If filament runs out, follow the printer's
   unloading/loading prompts with the same PLA type. Do not remove the USB drive
   or turn off power during normal printing. In an immediate hazard, stop the
   machine and disconnect power if safe to do so.

## Finish and assemble

1. Wait for the completion screen and for the bed and parts to cool.
2. Remove the steel sheet and gently flex it to release the print. Support the
   boat under the hulls; do not pull it free by its thin crossbeams or skeg.
3. Remove brim and steering supports carefully. The vane plate is only 1 mm
   thick. Trim and lightly deburr holes without enlarging them unnecessarily.
4. Clear every plastic fragment from the sheet and heatbed before the next job.
   Refit and clean the sheet, then repeat the Print steps for the other file.
5. Check the body for gaps or sagging near the hollow floats and beam transitions.
   Weigh it after removing waste. The design's approximately 75 g body and 106 g
   all-up targets are estimates, not the slicer's measured result or a guarantee.
6. Test flotation and leakage in a shallow container before adding the rig or
   sailing. A closed CAD mesh is not proof of a watertight FDM print. If it seeps,
   follow the sealing advice in the [design specification](docs/design-spec.md).
   Recheck total weight and balance after assembly.

## Change settings or regenerate

Open the relevant project **as a project**, not just imported geometry, in
PrusaSlicer 2.9.6 or newer:

- [Body project](print/projects/Lahar_Body_COREONEplus_PLA_04.3mf)
- [Steering project](print/projects/Lahar_Steering_COREONEplus_PLA_04.3mf)

The projects include the objects, layout, modifiers, and full resolved settings.
Prusa calls the printer preset **Prusa CORE One HF0.4 nozzle**; its bundled model
definition explicitly covers **CORE One and CORE One+**. Do not select CORE One L.

Both jobs use 0.15 mm layers throughout, a 0.20 mm first layer, two perimeters,
four top and bottom layers, and a 3 mm outer brim. The body has 4% gyroid infill
with two exact side-float modifiers at 0%; supports are off. Steering has 15%
infill and automatic snug supports from the build plate, with a 0.20 mm contact
gap. Bridge speed is 20 mm/s. Do not replace all infill with a uniform value or
scale the parts: flotation and hardware fits depend on these choices.

Review the first layer, supports, hollow closures, and bridge regions in Preview.
The body warning must be judged with a test print; simply enabling supports can
leave inaccessible support inside its hollow regions. If bridges fail, stop and
revise the local slicing or design before trying again. Export new G-code after
any change; changing a 3MF does not update the existing USB files.

The [five STLs](print/stl/) are already in millimetres and print-oriented. Do not
flip the exported body a second time. They do not carry the infill modifiers or
printer settings. The [source macro](cad/lahar.FCMacro) remains in sailing
orientation; its ellipse-axis construction was corrected to make this export work.
The measured body mesh is 200 x 197.29 x 45.63 mm; interpolated curves differ
slightly from the nominal dimensions in the original design notes.

For a reproducible rebuild from the repository root, use
[export_print.py](cad/export_print.py) with FreeCAD's Python environment and then
[slice_print.py](cad/slice_print.py) with ordinary Python 3.10+:

```sh
"$FREECAD_PYTHON" boats/lahar/cad/export_print.py --amf-dir "$WORK"
python3 boats/lahar/cad/slice_print.py \
  --slicer "$PRUSA_SLICER" --profiles "$PRUSA_PROFILES" --amf-dir "$WORK"
```

Set these variables to your FreeCAD Python executable, a temporary working
directory, the PrusaSlicer command-line executable, and its bundled PrusaResearch
profile INI. The FreeCAD environment must be able to import FreeCAD, Part, and
MeshPart; a stock Python installation cannot. With a Windows slicer launched
from WSL, put the working directory on a Windows-mounted drive. Rebuilding
overwrites the generated STLs, projects, and G-code in this boat's print folder.

Prepared using **FreeCAD 1.1.3 and official PrusaSlicer 2.9.6** on 2026-09-11.
Checks included valid single CAD solids, closed/manifold meshes, project
round-tripping, preserved zero-infill modifiers, actual steering support paths,
and extrusion bounds inside the 250 x 220 x 270 mm build volume. No physical
printer, thumb drive, hardware fit, or flotation test was performed.

## Official references

- [CORE One+ support and current downloads](https://help.prusa3d.com/product/core-one-plus)
- [CORE One+ handbook 1.02](https://www.prusa3d.com/downloads/manual/prusa3d_manual_core_one_plus_1_02_en.pdf), sections 5.5-5.8 and 6.1
- [Prusa USB drive formatting](https://help.prusa3d.com/article/sd-cards-and-usb-drives_112291)
- [Prusa PLA material guidance](https://help.prusa3d.com/article/pla_2062)
- [Official PrusaSlicer 2.9.6 release](https://github.com/prusa3d/PrusaSlicer/releases/tag/version_2.9.6)

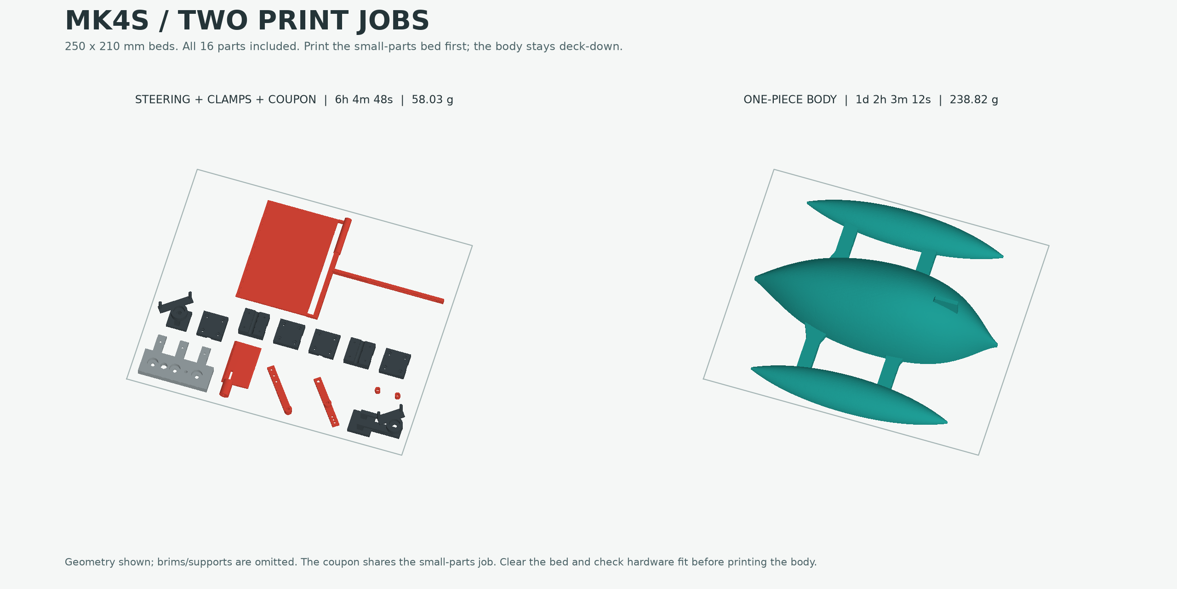
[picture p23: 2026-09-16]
boats/lahar/v2/renders/print-layouts.png

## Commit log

2026-09-11 adding print files for Prusia Core One Plus"
    [Lahar_Body_COREONEplus_PLA_04.3mf, Lahar_Steering_COREONEplus_PLA_04.3mf, Rudder_Blade.stl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]
2026-09-16 updating lahar v2 print for Prusa Core One Plus
2026-09-22 modifying steering to prevent print failures
